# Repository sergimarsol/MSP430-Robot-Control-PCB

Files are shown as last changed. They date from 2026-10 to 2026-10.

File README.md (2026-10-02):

# MSP430 Robot Control PCB

**A custom two-layer KiCad control board and bare-metal C firmware for the MSP430FR2355. It drives a mobile robot in joystick, line-following and light-following modes, using an LCD menu and an interrupt-driven I2C bus.**

<p align="center">
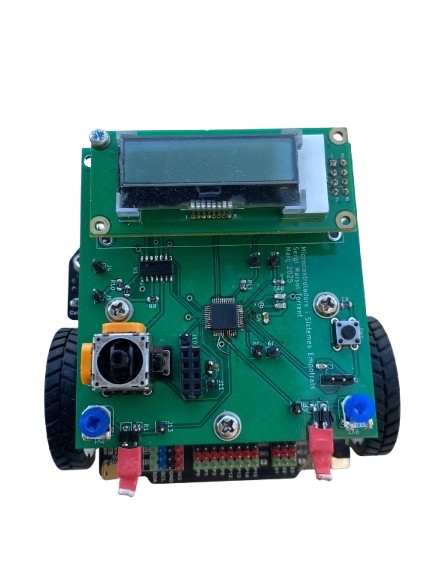
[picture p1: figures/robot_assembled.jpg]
Assembled control PCB mounted on the robot base
  
</p>

## Overview

The goal: design a controller board for a mobile robot base, have it fabricated, assemble it, and write bare-metal firmware that lets a user pick an operating mode from an on-board menu and then either drive the robot by hand or let it run autonomously.

I did the whole project alone: block diagram, schematic, PCB layout, assembly, hardware debugging, and every firmware driver.

## What I built

- **Custom control PCB (KiCad).** I designed the schematic and two-layer layout around the 48-pin MSP430FR2355TPT. The board has:
  - a 32.768 kHz crystal and a Spy-Bi-Wire (SBW) programming header with a reset button,
  - a 16x2 I2C LCD,
  - a THB001P analog joystick conditioned by LMV324 comparators,
  - two LDR + trimmer voltage dividers on ADC inputs,
  - a 14-pin connector to the robot base, an ESP-01 (UART) footprint, and test points on the key signals.

  I ran ERC/DRC, generated the Gerbers and had the board fabricated and assembled.
- **Board bring-up and hardware fix.** During bring-up I found that the two LDR traces had been routed to pins without ADC capability. I replaced the microcontroller and reworked two tracks so the light sensors reach ADC channels A10/A11 (P5.2/P5.3).
- **Interrupt-driven I2C master driver.** eUSCI_B1 runs as an I2C master on P4.6/P4.7 at about 100 kHz (SMCLK 16 MHz / 160). TX and RX are handled in the ISR while the CPU sleeps in LPM0. One `I2C_send`/`I2C_receive` pair serves all peripherals:
  - the robot base at address `0x10`: motors (command `0x00`), RGB LEDs (`0x0B`) and line sensors (`0x1D`),
  - the LCD at `0x3E`.
- **Clock and timing.** The DCO runs at 16 MHz via an FLL referenced to the external 32.768 kHz crystal. Timer B0 gives a 1 ms tick that drives `delay_ms()`.
- **Light following (ADC).** The ADC converts at 12 bits and the ADC ISR alternates between the two LDR channels, averaging 16 samples per channel. The robot turns toward the brighter side when the left–right difference is more than ±250 counts, and goes straight otherwise. It shows live `L=… | R=…` readings on the LCD.
- **Line following.** The firmware reads the base's ground-sensor byte over I2C, masks the six sensor bits, and maps the patterns to forward, left, right or stop.
- **Joystick control and LCD menu.** The four comparator outputs of the joystick raise falling-edge interrupts on P2.0–P2.3, and the push button raises one on P1.5. Up/down cycles through the three modes; each mode has its own LED colour (red, green or blue) and LCD label, and the button confirms the choice.

## How it works

```mermaid
flowchart LR
    subgraph PCB["Custom control PCB"]
        MCU["MSP430FR2355<br/>16 MHz DCO / FLL"]
        XT["32.768 kHz crystal"] --> MCU
        JOY["THB001P joystick"] --> CMP["LMV324 comparators"] -->|"P2.0-P2.3 IRQ"| MCU
        BTN["Push button"] -->|"P1.5 IRQ"| MCU
        LDR["2x LDR + trimmer"] -->|"ADC A10/A11"| MCU
        SBW["SBW header + reset"] --- MCU
        ESP["ESP-01 footprint<br/>(UART, not used)"] -.- MCU
    end
    MCU -->|"I2C 0x3E"| LCD["16x2 LCD"]
    MCU -->|"I2C 0x10"| BASE["Robot base controller"]
    BASE --> MOT["2 DC motors"]
    BASE --> LED["2 RGB LEDs"]
    BASE -->|"sensor byte"| LINE["Line sensors"]
```

### Operating modes (`main.c`)

```mermaid
stateDiagram-v2
    [*] --> Init: clocks, timer, I2C, LEDs, motors, joystick, ADC, LCD
    Init --> Menu: "Main Menu" splash (3 s)
    Menu --> Menu: joystick up/down cycles mode
    Menu --> Joystick: button, mode 0 (LEDs red)
    Menu --> FollowLines: button, mode 1 (LEDs green)
    Menu --> FollowLight: button, mode 2 (LEDs blue)
    Joystick --> Joystick: forward/back/left/right/stop every 100 ms
    FollowLines --> FollowLines: read 6-bit sensor pattern over I2C
    FollowLight --> FollowLight: compare averaged LDR readings
```

### I2C message formats

| Target | Address | Payload |
|---|---|---|
| Motors | `0x10` | `0x00, dirL, speedL, dirR, speedR` (speed 0–255) |
| RGB LEDs | `0x10` | `0x0B, colourL, colourR` (OFF, RED, GREEN, YELLOW, BLUE, PURPLE, PINK, WHITE = `0x00`–`0x07`) |
| Line sensors | `0x10` | write `0x1D`, then read 1 byte (one bit per sensor) |
| LCD | `0x3E` | `0x00` + command bytes, or `@` + ASCII text |

## Hardware

| Schematic | PCB 3D render (top) | PCB 3D render (bottom) |
|---|---|---|
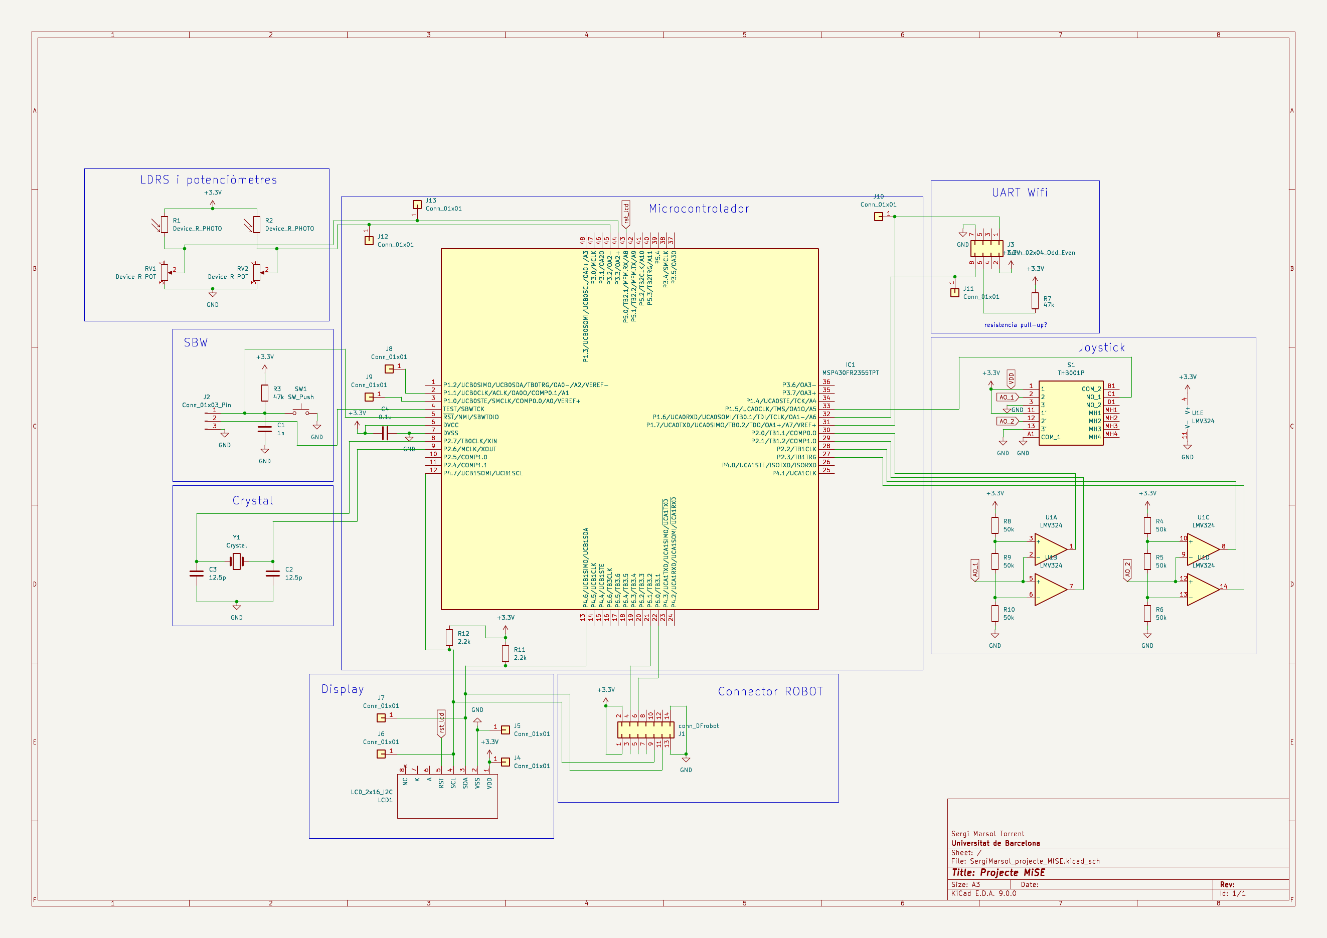
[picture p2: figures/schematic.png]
Full schematic
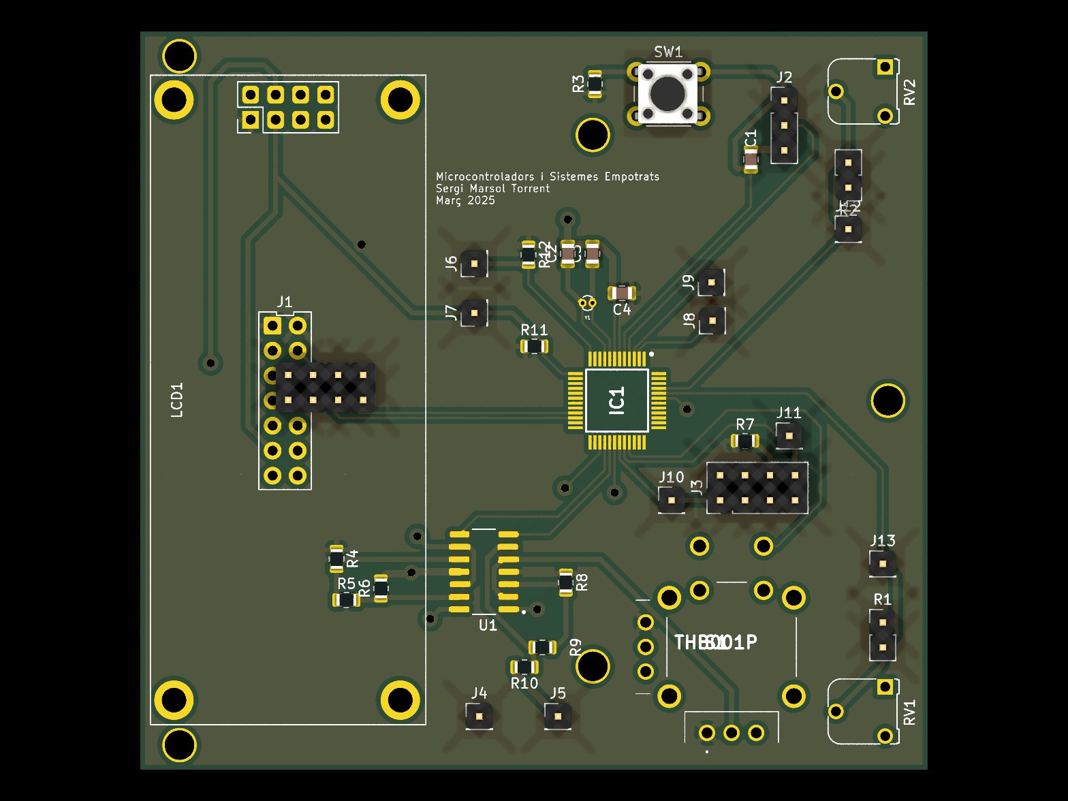
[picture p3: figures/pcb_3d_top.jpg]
3D render, top
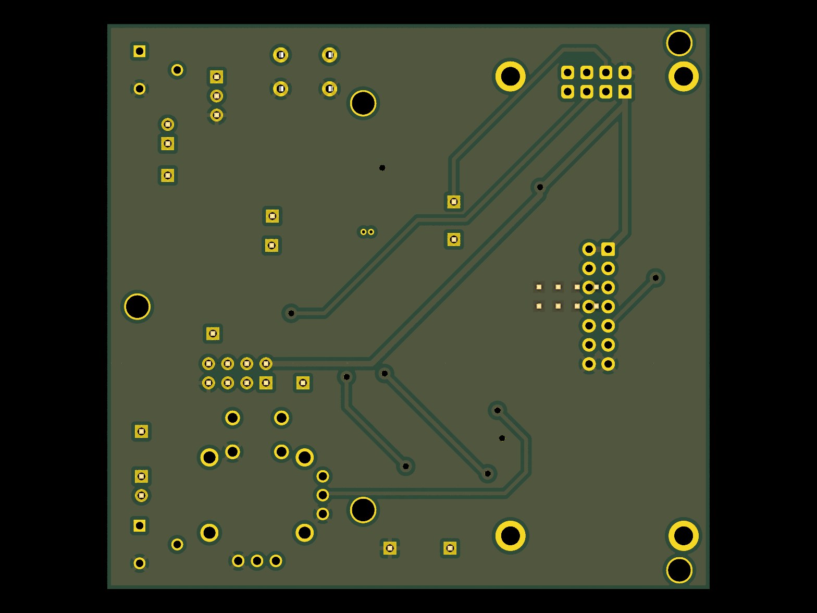
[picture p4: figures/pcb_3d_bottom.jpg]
3D render, bottom
|  |  |  |

| Block | Implementation |
|---|---|
| MCU | MSP430FR2355TPT (LQFP-48), 3.3 V, decoupling next to the supply pins |
| Clock | 32.768 kHz crystal, 12.5 pF load capacitors |
| Programming | 3-pin Spy-Bi-Wire header; reset button with 47 kΩ pull-up |
| Display | 16x2 I2C LCD (Midas, MCCOG controller), hardware reset line from the MCU |
| Joystick | THB001P, analog axes thresholded by LMV324 comparators into interrupt-capable GPIOs |
| Light sensors | 2 LDRs, each in a divider with a trimmer, read by the ADC |
| Robot connector | 14-pin DFRobot connector: VCC, GND, I2C SDA/SCL, 2 GPIOs |
| Wi-Fi | ESP-01 on UART, placed on the board but **not implemented in firmware** |
| Debug | Single-pin test points on the main signals |

Layout rules, from the PCB design report:
- Board outline at most 75 × 80 mm.
- Track widths: 0.75 mm for power and GND, 0.5 mm for signals, 0.25 mm minimum.
- Clearance: 0.2 mm between tracks and pads, 0.3 mm to copper zones.
- VCC pour on the front copper layer and GND pour on the back.
- No right-angle tracks.
- MCU and op-amp in the centre of the board, connectors at the edges.

## Firmware architecture

| Module | Responsibility |
|---|---|
| `main.c` | Initialise peripherals, LCD menu, mode selection, main control loop |
| `timer.c/.h` | 16 MHz clock setup (FLL + XT1), Timer B0 1 ms ISR, `delay_ms()` |
| `i2c.c/.h` | eUSCI_B1 I2C master, interrupt-driven `I2C_send` / `I2C_receive` |
| `lcd.c/.h` | LCD initialisation, text, line change, clear, formatted values, 1- and 2-line helpers |
| `leds.c/.h` | RGB LED colour commands |
| `motors.c/.h` | Motor command packet plus `forward`, `backward`, `turn_left`, `turn_right`, `stop` |
| `joystick.c/.h` | Joystick and stop-button GPIO interrupts, joystick-driven motion |
| `ADC.c/.h` | 12-bit ADC on two LDR channels, 16-sample averaging ISR, light-following control |
| `sensors.c/.h` | Line-sensor read over I2C, line-following control |

The CCS build map committed in `firmware/Debug/` reports about 4.0 KB of the 32 KB FRAM and 203 bytes of the 4 KB RAM in use.

## Tech stack

- **MCU:** TI MSP430FR2355
- **Firmware:** C (bare-metal, register level), TI Code Composer Studio 12.8 with TI MSP430 compiler 21.6.1 LTS
- **EDA:** KiCad 9 (schematic, layout, 3D, Gerbers)
- **Interfaces:** I2C, ADC, GPIO interrupts, timers, low-power modes

## Repository structure

```
.
├── firmware/                  # C sources and headers for every driver
│   ├── main.c
│   ├── ADC.c/.h  i2c.c/.h  joystick.c/.h  lcd.c/.h
│   ├── leds.c/.h  motors.c/.h  sensors.c/.h  timer.c/.h
│   ├── lnk_msp430fr2355.cmd   # Linker command file
│   ├── targetConfigs/         # CCS debug-probe target configuration
│   └── Debug/                 # CCS build output (generated)
├── hardware/
│   ├── robot_control_board.kicad_pro / .kicad_sch / .kicad_pcb
│   ├── gerbers/    # Fabrication outputs (Gerbers + drill)
│   ├── libraries/MiSE.pretty/ # Course-provided footprint library
│   └── fp-lib-table           # Points to the project-relative MiSE library
├── figures/                   # README images (rendered from KiCad and the presentation)
├── documents/
│   └── presentation.pdf       # Final project presentation (Catalan)
├── LICENSE
└── README.md
```

## Getting started

### Hardware
1. Install **KiCad 9** or newer. The project files were saved with KiCad 9.0.
2. Open `hardware/robot_control_board.kicad_pro`. The `MiSE` footprint library resolves automatically through `${KIPRJMOD}/libraries/MiSE.pretty`.
3. Ready-to-send fabrication files are in `hardware/gerbers/`.

### Firmware
The repository holds the sources only, not the CCS `.project`/`.cproject` files, so you build them in a new project:
1. In Code Composer Studio, create a new **MSP430FR2355** project (empty C project).
2. Copy the `.c`/`.h` files from `firmware/` into it, plus `lnk_msp430fr2355.cmd` (or use the linker file CCS generates for the device).
3. Build, connect an MSP-FET or a LaunchPad eZ-FET to the board's SBW header, and click **Debug** to flash.
4. On boot the LCD shows the main menu. Move the joystick up/down to choose a mode and press the button to start it.

## Status and limitations

- The ESP-01 Wi-Fi module is on the PCB, but there is no UART or Wi-Fi code.
- Motor speed is fixed at 50/255 in every mode. Control is reactive (bang-bang), with no closed-loop speed control.
- The ±250-count light threshold and the line-sensor bit patterns were tuned by hand for the lab setup.

## Acknowledgements

- Developed for *Microcontrollers and Embedded Systems* (Electronic & Telecommunications Engineering, Universitat de Barcelona, spring 2025).
- The robot base (motor, LED and line-sensor controller reachable over I2C) and the `MiSE.pretty` footprint library came with the course.
- Author: **Sergi Marsol** (individual project).

## License

Released under the [MIT License](LICENSE). The course-provided footprint library in `hardware/libraries/MiSE.pretty/` keeps its original terms.

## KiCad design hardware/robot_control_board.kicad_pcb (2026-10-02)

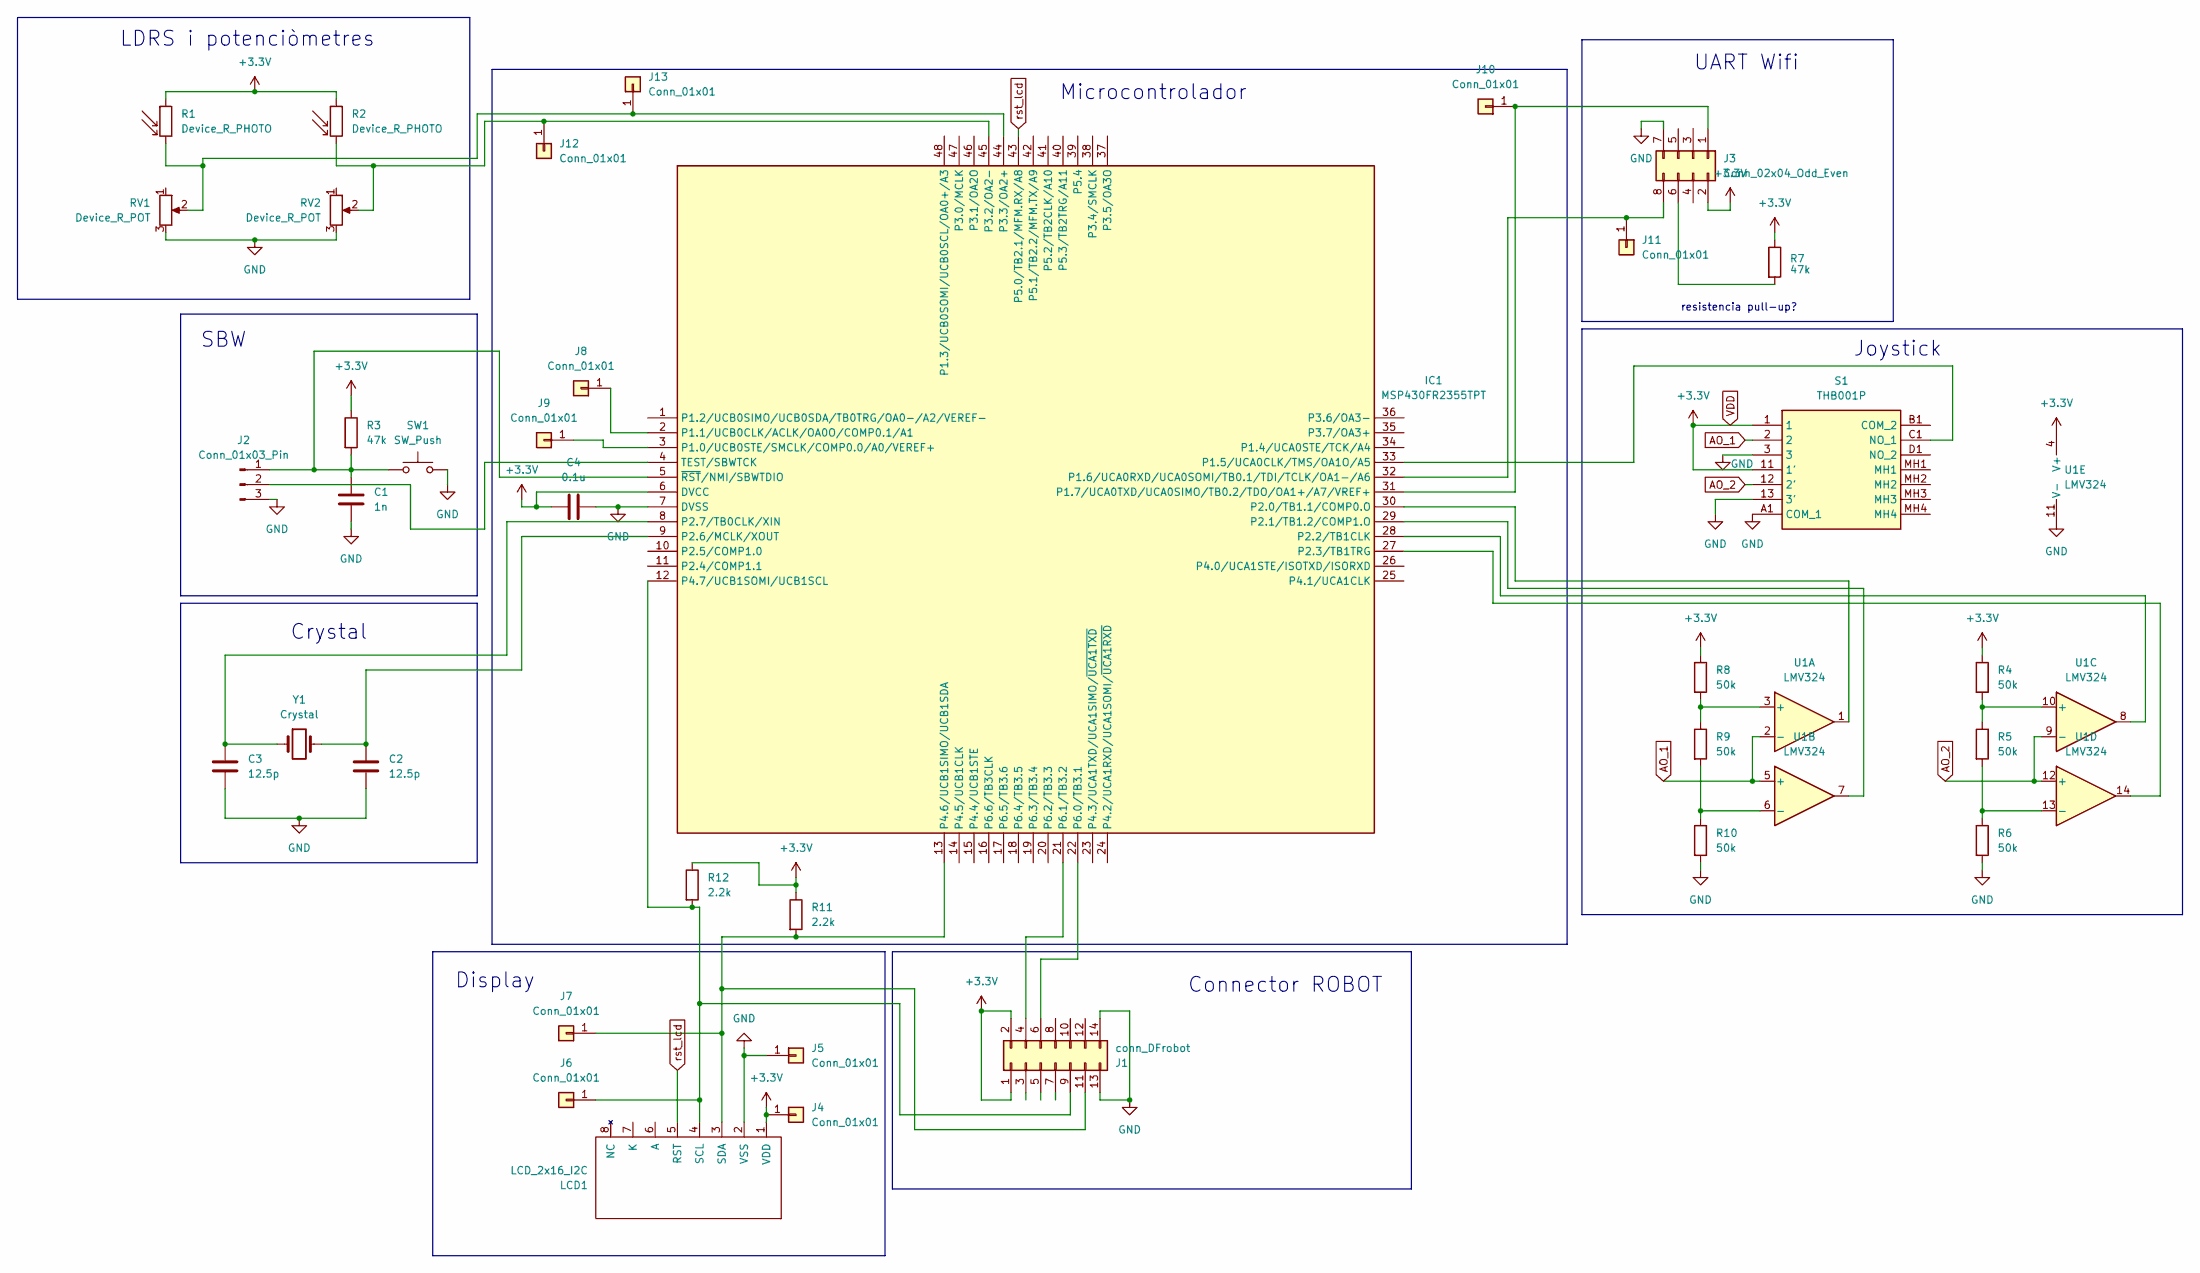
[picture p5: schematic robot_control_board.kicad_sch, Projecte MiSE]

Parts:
C1: 1n; C_0805_2012Metric
C2, C3: 12.5p; C_0805_2012Metric
C4: 0.1u; C_0805_2012Metric
IC1: MSP430FR2355TPT; QFP50P900X900X160-48N; Manufacturer_Part_Number MSP430FR2355TPT; Mouser Part Number 595-MSP430FR2355TPT
J1: conn_DFrobot
J2: Conn_01x03_Pin; PinHeader_1x03_P2.54mm_Vertical
J3: Conn_02x04_Odd_Even; PinHeader_2x04_P2.54mm_Vertical
J4, J5, J6, J7, J8, J9, J10, J11, J12, J13: Conn_01x01; PinHeader_1x01_P2.54mm_Vertical
LCD1: LCD_2x16_I2C; LCD_2x16_I2C(Midas)
R1, R2: Device_R_PHOTO; LDR
R3, R7: 47k; R_0805_2012Metric
R4, R5, R6, R8, R9, R10: 50k; R_0805_2012Metric
R11, R12: 2.2k; R_0805_2012Metric
RV1, RV2: Device_R_POT; Trimmer_MiSE
S1: THB001P; Manufacturer_Part_Number THB001P; Mouser Part Number 611-THB001P
SW1: SW_Push; SW_PUSH_6mm_H4.3mm
U1: LMV324; SOIC127P600X175-14N
Y1: Crystal; XTAL_ECS-.327-8-14

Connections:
AO_1: S1.2, U1.2 (-), U1.5 (+)
AO_2: S1.12 (2'), U1.9 (-), U1.12 (+)
GND: C1.2, C2.2, C3.2, C4.2, IC1.7 (DVSS), J1.13, J1.14, J2.3, J3.7, J5.1, LCD1.2 (VSS), R6.2, R10.2, RV1.3, RV2.3, S1.3, S1.13 (3'), S1.A1 (COM_1), SW1.2, U1.11 (V-)
unnamed: IC1.3 (P1.0/UCB0STE/SMCLK/COMP0.0/A0/VEREF+), J9.1
unnamed: IC1.2 (P1.1/UCB0CLK/ACLK/OA0O/COMP0.1/A1), J8.1
unnamed: IC1.33 (P1.5/UCA0CLK/TMS/OA1O/A5), S1.C1 (NO_1)
unnamed: IC1.32 (P1.6/UCA0RXD/UCA0SOMI/TB0.1/TDI/TCLK/OA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), J3.8, J11.1
unnamed: IC1.31 (P1.7/UCA0TXD/UCA0SIMO/TB0.2/TDO/OA1+/A7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), J3.1, J10.1
unnamed: IC1.30 (P2.0/TB1.1/COMP0.O), U1.1
unnamed: IC1.29 (P2.1/TB1.2/COMP1.O), U1.7
unnamed: IC1.28 (P2.2/TB1CLK), U1.8
unnamed: IC1.27 (P2.3/TB1TRG), U1.14
unnamed: C2.1, IC1.9 (P2.6/MCLK/XOUT), Y1.2
unnamed: C3.1, IC1.8 (P2.7/TB0CLK/XIN), Y1.1
unnamed: IC1.45 (P3.2/OA2-), J12.1, R2.2, RV2.2
unnamed: IC1.44 (P3.3/OA2+), J13.1, R1.2, RV1.2
unnamed: IC1.13 (P4.6/UCB1SIMO/UCB1SDA), J1.11, J7.1, LCD1.3 (SDA), R11.2
unnamed: IC1.12 (P4.7/UCB1SOMI/UCB1SCL), J1.9, J6.1, LCD1.4 (SCL), R12.2
unnamed: IC1.22 (P6.0/TB3.1), J1.6
unnamed: IC1.21 (P6.1/TB3.2), J1.4
unnamed: IC1.4 (TEST/SBWTCK), J2.2
unnamed: C1.1, IC1.5 (~RST/NMI/SBWTDIO), J2.1, R3.2, SW1.1
unnamed: J3.6, R7.2
unnamed: R8.2, R9.1, U1.3 (+)
unnamed: R9.2, R10.1, U1.6 (-)
unnamed: R4.2, R5.1, U1.10 (+)
unnamed: R5.2, R6.1, U1.13 (-)
VDD: C4.1, IC1.6 (DVCC), J1.1, J1.2, J3.2, J4.1, LCD1.1 (VDD), R1.1, R2.1, R3.1, R4.1, R7.1, R8.1, R11.1, R12.1, S1.1, S1.11 (1'), U1.4 (V+)
rst_lcd: IC1.43 (P5.0/TB2.1/MFM.RX/A8), LCD1.5 (RST)

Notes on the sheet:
UART Wifi
Crystal
Display
SBW
LDRS i potenciòmetres
resistencia pull-up?
Connector ROBOT
Microcontrolador
Joystick

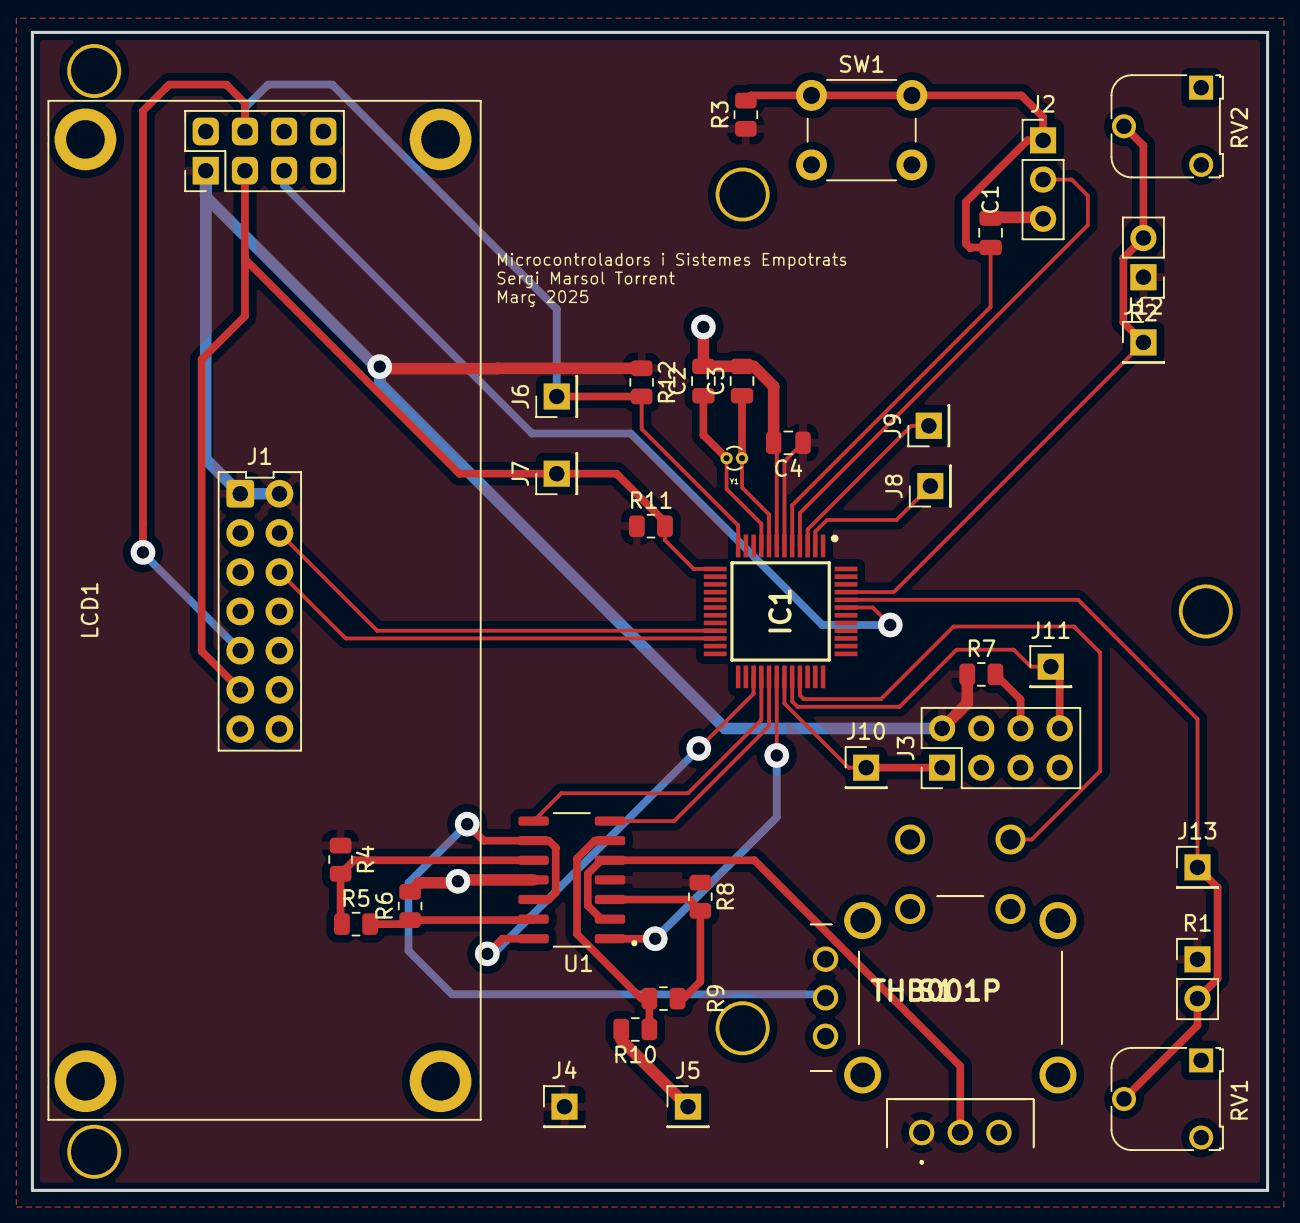
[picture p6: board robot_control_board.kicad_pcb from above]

Board: 2 copper layers, 80.0 x 75.0 mm, 37 parts (0 on the bottom side), 29 nets.

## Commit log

2026-10-01 Make KiCad footprint library path project-relative; remove KiCad cache and backups
2026-10-02 Use descriptive file, module and section names; move course context to acknowledgements
    [robot_control_board-B_Cu.gbr, robot_control_board-B_Mask.gbr, robot_control_board-Edge_Cuts.gbr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]
